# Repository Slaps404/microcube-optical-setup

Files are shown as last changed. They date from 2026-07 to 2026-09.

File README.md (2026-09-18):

# uCube optical setup

Parametric OpenSCAD parts for a 50 mm plate beamsplitter, M37 camera interface,
and a focus-adjustable illumination cell. The design is built around the
official uCube library and the measured 45 mm clear opening cube.

## Source of truth

- `optical_setup.scad` is the editable geometry source of truth.
- `DESIGN.md` records the active architecture, measured dimensions, provisional
  dimensions, and required physical tests.
- `exports/current` contains the tracked active printable STL pack. Historical
  `adjustable_*` files remain in that folder but are explicitly excluded in its
  README.

## Layout

- `optical_setup.scad`: all printable parts and assembly previews.
- `vendor/uCube`: official uCube library, with local fixes in `PATCHES.md`.
- `vendor/BOSL2`: pinned M37 thread-geometry dependency.
- `research`: sourced illumination research.
- `exports/current`: tracked printable STLs and their OpenSCAD entry files.
- `slicer`: resolved Ender 3 V2 profiles for 0.4, 0.2, and 0.1 mm nozzles.
- `scripts`: reproducible STL export, mesh checks, and slicer smoke tests.
- `previews/current`: curated images for documentation. Other QA renders under
  `previews/` are ignored by Git.

Initialize dependencies after cloning:

```sh
git submodule update --init --recursive
```

OpenSCAD is required for previews, validation, and STL export. On macOS with
Homebrew:

```sh
brew install openscad
```

## Active design

The optical cube uses the measured uCube geometry:

| Feature | Value |
| --- | --- |
| Clear through-hole | 45 mm |
| Frame feature | 7 mm |
| Overall cube | 73 mm |
| uFace plate | 59 x 59 x 3.5 mm |
| uFace corner screw centers | +/-26 mm |
| Mid-edge cube-to-cube screw centers | +/-29.5 mm |

The bottom uFace holds a measured 50 x 50 x 2.5 mm plate beamsplitter at 45
degrees. Its 2.4 mm printed slot is intentionally 0.1 mm undersized for final
fit by light filing.
The camera uFace provides a male M37 x 0.75 thread for the lens's female
front/filter thread. This is separate from the lens's camera-side C-mount.

Illumination uses a custom, light-tight cell bolted to one side uFace, not a
second official cube. The cell is 190 mm long, with a 180 mm clear interior
rail, and prints as two U shells: a
bottom shell with the mating plate, floor, far wall, and integral rail; and a
top shell that acts as the removable lid. The lid has five 45-degree-baffled
roof exhaust slots and four low side-intake slots behind an internal shroud.
A tongue-and-groove seam blocks a straight light path.

One centered 10.5 x 9 mm rail carries two independently clamped sliders:

- A 25 mm-deep lens sleeve for a purchased 40.0 mm lens tube. Its 1 mm inner
  lip stops the tube, and a 1.25 mm-wide internal spring-clip groove 5.25 mm in
  from the open rear retains it.
- An LED post for the 20 mm star MCPCB, with a cable pass-through below it.

Both sliders use opposing M3 heat-set-insert clamp screws. Their positions are
set on the bench to tune focus and illumination, rather than assumed from
optical estimates. The sleeve harness spans the full sleeve depth to center its
mass over the rail contact. The LED feature remains offset on its harness to
create one coplanar end face for support-free print orientation without
changing the modeled optical position.

The harness side runners rest directly on the bottom-U floor. The current
model gives a nominal 9 mm harness slot depth around the measured 9 mm rail,
so the slider seats on both the floor and the rail top.

Modes 2 through 4 are legacy compact-light parts. They remain in the source,
but are not part of the active design.

## Render modes

Set `render_mode` near the top of `optical_setup.scad`.

| Mode | Output |
| --- | --- |
| 0 | Complete optical assembly |
| 1 | Beamsplitter mounting face |
| 2-4 | Legacy compact light chamber parts |
| 5 | M37 camera mounting face |
| 6 | M37 thread-fit coupon |
| 7 | Exploded assembly reference |
| 8 | Inspection assembly reference |
| 9 | Official uCube shell |
| 10 | Illumination cell bottom U shell |
| 11 | Illumination cell top U shell, lid |
| 12 | Lens sleeve slider |
| 13 | LED post slider |
| 14 | Illumination cell assembly, lid on |
| 15 | Illumination cell assembly, lid off |

Modes 0, 7, 8, 14, and 15 are assembly or inspection views, not standalone
print parts. Export the other modes individually.

## Validate before exporting

Run a hard-warning validation before exporting an STL:

```sh
openscad --hardwarnings -o /tmp/optical_setup.csg optical_setup.scad
```

After changing geometry, render and inspect front, back, left, right, top, and
isometric previews. OpenSCAD validity confirms the model can render, not that
printed parts will fit.

Regenerate every active STL, check that each mesh is one connected watertight
surface, and run the Ender 3 V2 slicer smoke tests with:

```sh
scripts/export_printables.sh
scripts/slice_smoke_test.sh
```

GitHub Actions runs both commands and publishes the validated STL pack as a
build artifact. Slicer success catches toolpath and build-volume failures, but
does not replace physical fit coupons or first-layer calibration.

## Physical tests required

An initial cell and slider prototype has been printed. The revised 0.3 mm rail
fit and 25 mm sleeve still require physical verification. Test these coupons or
fit-critical features before another full print:

- One custom uFace on the physical cube, confirming outward-facing
  counterbores and fully seated screw heads.
- A rail segment and slider foot, confirming hand-sliding motion and secure
  clamp without rocking.
- A shallow lens sleeve, confirming the 40.0 mm tube slips in with minimal
  play.
- The M37 thread coupon, before the full camera face.
- Short bottom and lid seam sections, confirming the lid seats and blocks
  daylight.
- The 2.4 mm beamsplitter slot against the 2.5 mm plate, filing only enough for
  a secure seated fit.

Several values remain provisional, including heat-set insert dimensions,
optical clear aperture and focal data, cable routing, and the final focus
distances. See `DESIGN.md` for the full risk and test record.

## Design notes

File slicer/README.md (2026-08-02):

# Ender 3 V2 slicer smoke-test profiles

These are resolved PrusaSlicer profiles for an Ender 3 V2 using generic PLA
Pro assumptions. They exist to make slicing repeatable and to catch impossible
toolpaths, bed-size violations, disconnected meshes, and support requirements.

| Profile | Nozzle | Layer height | Intended parts |
| --- | ---: | ---: | --- |
| `ender3v2-pla-pro-04.ini` | 0.4 mm | 0.20 mm | Cell shells, cube, beamsplitter face |
| `ender3v2-pla-pro-02.ini` | 0.2 mm | 0.10 mm | Sliders and M37 camera face |
| `ender3v2-pla-pro-01.ini` | 0.1 mm | 0.05 mm | M37 thread-fit coupon |

All profiles use 205 C nozzle, 60 C bed, and three perimeters. Confirm the
temperature range printed on the actual PLA Pro spool before printing. These
profiles are smoke-test defaults, not a substitute for first-layer, flow,
retraction, and dimensional calibration on the physical printer.

Run:

```sh
scripts/export_printables.sh
scripts/slice_smoke_test.sh
```

Generated G-code is written under `build/` and intentionally ignored by Git.
Do not send CI-generated G-code directly to a printer without previewing it.

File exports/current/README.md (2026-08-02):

# Current printable STL pack

Generated from `optical_setup.scad`. Dimensions are millimeters. Each STL has a
matching SCAD entry file in this folder. The SCAD entry files load the shared
parametric source from the repository, so keep the repository structure intact.

The active Path B illumination cell is a four-part print, listed first below.

| File | Quantity | Render mode | Purpose |
| --- | ---: | ---: | --- |
| `illumination_cell_bottom_u.stl` | 1 | 10 | Cube-facing bottom cell, fused standard uFace, full-depth screw bores, floor, rail, and far wall |
| `illumination_cell_top_u.stl` | 1 | 11 | Cell lid, left wall, right wall, and roof only |
| `lens_sleeve_slider.stl` | 1 | 12 | 41 mm lens-tube sleeve and raised-clamp rail harness |
| `led_post_slider.stl` | 1 | 13 | LED post, bottom-open cable notch, and raised-clamp rail harness |
| `official_ucube_shell.stl` | 1 | 9 | Optical cube shell |
| `beamsplitter_mounting_face.stl` | 1 | 1 | Bottom 50 mm beamsplitter carrier face |
| `m37_camera_mounting_face.stl` | 1 | 5 | Camera face with male M37 x 0.75 thread |
| `m37_thread_fit_coupon.stl` | 1 optional | 6 | Short thread-fit test before printing the camera face |
The earlier `adjustable_*` and `collimator_retaining_ring` files are retained
only as historical exports. Do not print them for the active Path B cell.

## Ender 3 V2 slicer assignments

| Parts | Nozzle | Layer | Orientation and supports |
| --- | ---: | ---: | --- |
| Cell bottom, cube shell | 0.4 mm | 0.20 mm | As exported, automatic build-plate-only supports |
| Cell lid | 0.4 mm | 0.20 mm | Rotate X 180 degrees so the roof is on the bed |
| Beamsplitter face | 0.4 mm | 0.20 mm | As exported, no supports |
| Lens slider | 0.2 mm | 0.10 mm | Rotate Y 90 degrees, 3 mm brim, build-plate-only supports |
| LED slider | 0.2 mm | 0.10 mm | As exported, 3 mm brim, no supports |
| M37 camera face | 0.2 mm | 0.10 mm | As exported, no supports |
| M37 thread coupon | 0.1 mm | 0.05 mm | As exported, 2 mm brim, no supports |

The checked-in PrusaSlicer profiles assume 205 C nozzle, 60 C bed, and three
perimeters. Confirm temperatures against the actual PLA Pro spool. CI-generated
G-code is a smoke test and must not be sent directly to the printer without a
slicer preview and physical first-layer calibration.

Print the thread coupon and fit-critical rail, lens-pocket, and beamsplitter
features as tests before committing to the complete print. M3 insert pockets,
thermal hardware, focal spacing, and several rail anchor dimensions remain
provisional in the OpenSCAD source.

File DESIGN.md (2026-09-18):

# Microcube Optical Setup: Design Record

> **Status:** Active design context, pending physical prototype review
> **Updated:** 2026-08-14
> **Note:** Renamed from `proposed_plan.md`; the design is no longer a proposal.

---

## 1. Objective

A parametric, printable OpenSCAD optical assembly built around the official
uCube library. A 50 mm plate beamsplitter folds an illumination beam into a
camera path. Success means the parts align on the cube optical center, export as
valid individual STLs, and can be tuned on the bench without redesigning the
whole assembly.

Only mechanical 3D design is in scope. Raspberry Pi timing, LED driver
electronics, image acquisition, and image-combination logic are out of scope,
except that the printed design must permit cable routing and external thermal
hardware.

## 2. Cube geometry (MEASURED and locked)

The physical scaled cube is `size = 45, d = 7`. Two numbers that looked
contradictory describe two different features, and both measurements were right.

| Feature | Value |
| --- | --- |
| Clear square through-hole | 45 |
| Frame feature `d` | 7 |
| Overall cube | 73 |
| uFace plate | 59 x 59 x 3.5 |
| Corner screw centers (uFace mounting) | +/-26 |
| Mid-edge cube-to-cube screws | +/-29.5 |
| Outer surface to inner opening edge | 14 (`2d`) |
| Screw-pad inset width | 10.5 (`1.5d`) |
| Screw spec | `screwR 1.75, capR 3, capH 2.5, insertH 5, insertR 2` |
| faceGap | 0.4 |

The through-hole is `size` = 45. The wider inside-face inset is `size + 2d` = 59,
which measures about 60 by hand. `Scaled_uCube.scad` in Downloads carries
`mySize = 60`, which conflates the two and is **stale**. Do not treat it as a
source of truth.

## 3. Architecture

### Optical cube
Official `uCube` shell. The bottom face carries the beamsplitter at 45 degrees,
the top face carries the M37 camera interface for the downward-looking camera,
and one side face carries the horizontal illumination cell.

### Illumination cell (Path B)
A **custom light-tight box that bolts into one uFace pocket**, not a second
official cube. Reason: an official 73 mm cube has 14 mm end walls, so its
interior is only 45 mm along the light axis, which cannot hold a 25 mm sleeve
plus focus travel plus the LED post. Bolting through a uFace keeps official
screw compatibility while letting the box be as long as the optics need.

Prints as **two U shells**:
- **Bottom U:** mating plate, near end wall with the light port, floor, far end
  wall, and the integral rail.
- **Top U:** both side walls plus the roof, dropping on as a lid.

The top U includes passive ventilation near the LED end: five 20 x 3 mm roof
exhaust slots with 45-degree internal louvers, plus four vertical 12 x 3 mm
intake slots low on the positive-Y wall behind an offset internal shroud. The
separated low intake and high exhaust encourage passive convection. Both vent
groups remove the direct perpendicular light path, but physical light-leak and
temperature tests are still required. The side shroud has a 5.5 mm air gap,
giving its clear downward plenum about 146 mm2 of area versus 144 mm2 across
the four intake slots, so the hidden channel does not choke the visible slots.

Assembly and focus adjustment happen by lifting the lid, so there is no access
slot or cover strip. The top U is intentionally only the roof and upper side
walls, with no end-wall tabs or cross-pieces.

The enclosure is 73 mm wide at the body but retains the standard 59 mm uFace
mounting plate and its unchanged screw pattern. The outer cell is 190 mm long,
giving the full-length rail 180 mm of clear sliding room. This is based on the
roughly 170 to 175 mm occupied span in the bench reference photo, rounded up to
leave a little positioning margin.

The cell uFace uses the same cube-opening datum as the other custom faces. A
44.2 mm square, 1 mm-deep bridge crosses the cell-wall/uFace interface and
overlaps each solid by 0.5 mm. This makes the mount and bottom shell one
printable part while retaining 0.4 mm clearance per side in the measured 45 mm
cube opening.

### Rail and sliders
**One** centered rail runs the full interior length along the light axis,
10.5 x 9 mm. Its top is *derived*, not chosen: it sits 1.5 mm below the sleeve
underside to leave a solid harness roof while the bore stays exactly on the beam
axis. The slot roof rests directly on the rail top, with no vertical clearance.

Two sliders share one `harness_foot` module, so they grip identically: a
nominal-zero-clearance U straddling the 10.5 mm rail with two opposing M3 set
screws in heat-set inserts pressing the rail flanks. The modeled slot is now
10.5 mm wide. The printed rail and harness showed approximately 10.4 mm and
11 mm respectively, so this revision is an empirical tightening experiment;
print a short coupon and file only if needed.

The harness side runners rest directly on the bottom-U floor. Their nominal
slot depth is 9 mm around the 9 mm rail, so the slider seats on both the floor
and the rail top.

The latest printed fit measured a 10.4 mm rail width and 10.85 mm harness slot
width, or 0.45 mm total lateral clearance. It also measured 9 mm rail depth
against the original 7 mm harness slot depth; the revised 9 mm slot closes
that unsupported lower span and brings the runners onto the floor datum.

The sleeve harness spans the full 25 mm sleeve depth, making both end faces
coplanar and centering the modeled mass over its rail contact for support-free
printing and stable unclamped placement. The LED upper geometry remains offset
toward positive X relative to its harness so the harness front is flush with
the LED pad face. The sleeve and LED optical planes remain fixed.

Each insert bore is intentionally stepped. The 4.0 mm by 5 mm insert pocket
ends at a 1 mm backing shoulder, followed by a 3.2 mm screw passage to the rail.
The 0.4 mm radial shoulder stops the insert and keeps it out of the sliding
slot. Both slider types use the shared `m3_insert_diameter_mm` and
`m3_insert_length_mm` parameters. Final fit still requires a coupon with the
purchased insert.

- **Slider 1, lens sleeve** (one printed part): bore 41, wall 2, OD 45, depth 25.
  A 1 mm internal lip at the cube-facing end stops the purchased tube; the tube
  loads from the open rear and a 1.25 mm-wide internal circumferential spring-clip
  groove retains it 5.25 mm in from that rear edge. The groove has a 0.5 mm
  radial recess, leaving 1.5 mm of sleeve wall.
- **Slider 2, LED post:** a 22.8 mm-wide flat plate, flush with the harness
  sides, with its pad on the beam axis and a cable pass-through below the star
  footprint. The 20 mm star retains 1.4 mm of support per side.

### Optics
The two lenses ride on spring clips inside a **purchased 40.0 mm lens tube**
(measured, smooth outer surface). Our sleeve holds that tube. We neither model
nor machine the tube.

### Light source
Amazon ASIN B0CL726PBP: 3 W 3535 emitter on a 20 mm star MCPCB, 3.0-3.4 V at
700 mA, 120 degrees, 8000-10000 K. For v1 the star is taped or glued to the
post. **v1 strobes the LED, so no secondary heatsink is modeled** and the star's
own MCPCB is the only thermal mass. Capturing the star's edges or adding a
glued-on heatsink is a v2 change to one small part, not to the cell.

A 120 degree emitter spills a cone far wider than the lens, so **closer is
brighter**. Travel toward zero gap is worth more than travel past 25 mm. V1 is
limited to short-duration operation. The passive vents reduce trapped heat but
do not replace a heatsink for continuous use.

### Camera interface
Male M37 x 0.75 printed thread engaging the lens's female front/filter thread.
The lens's camera-side C-mount is a separate interface.

## 4. Key decisions and rationale

| Decision | Chosen approach | Rationale |
| --- | --- | --- |
| Cube size | `size = 45, d = 7` | Physical measurement. The 60 in the Downloads file is the inset, not the bore. |
| Screw counterbores | Z mirror in `official_face_at_inside_plane()` | The vendor uFace opens counterbores on plate local +Z, but every custom face builds toward the cube interior on +Z, so cap screws could not seat from outside. One mirror fixes all five faces with no vendor edits. `uHolder.scad` performs the same flip. |
| Illumination packaging | Custom box on a uFace (Path B) | A second official cube has only 45 mm of usable length. Path B also gives 2 seams instead of 6 face perimeters to light-seal, a solid floor for the rail, and an interior we control. |
| Cube rescaling | Rejected | Print time and setup time are the binding constraints. Prefer local geometry changes. |
| Rail count | One centered rail | It bridges the center of one end to the center of the other, which also dissolves any collision with the corner inserts. |
| Rail height | Derived from the sleeve | Centering the bore on the beam axis outranks rail height. |
| Rail sliding fit | 0.3 mm total lateral, 0 mm vertical | Physical prints showed excessive play at 1.0 mm total. The tighter 0.15 mm-per-side slip fit reduces rocking; direct top seating prevents optical-axis drop before clamping. |
| Harness side depth | 9 mm slot depth around 9 mm rail, 0 mm floor clearance | Seats the side runners on the bottom-U floor while the slot roof seats on the rail top. |
| Beamsplitter fit | 2.4 mm printed slot for measured 2.5 mm plate | The intentional 0.1 mm interference is removed by light filing until the plate seats securely. |
| Lens retention | Purchased tube, spring clip, 1 mm lip, 1.25 mm-wide internal groove | The lip fixes the cube-facing end. The rear groove gives the clip a positive seat while retaining the tube-in-tube fit. |
| Sleeve wall | 2 mm | Path B frees the interior size, so the earlier 1 mm workaround is unnecessary and would print weak. |
| Focus adjustment | Two independently clamped sliders | Both LED and lens positions must be tuned empirically. |
| Thermal design | Baffled passive vents, no heatsink in v1 | Short-duration operation limits heat input. Low side intake and high roof exhaust reduce trapped heat, but continuous use still requires a measured thermal solution. |
| Slider print faces | Full-depth sleeve harness; offset LED feature | Coplanar end faces let both sliders print on their backs without supports. The full-depth sleeve foot also centers its modeled mass over the rail contact while preserving the optical plane. |
| Harness wall | 6 mm | A 5 mm heat-set insert cannot live in a 3 mm wall. Enforced by assert. |
| Harness insert shoulder | Retained | The insert pocket needs a depth stop; the smaller continuation gives the clamp screw access to the rail. |
| Cell-to-cube interface | Standard uFace plus 44.2 mm bridge | The uFace enters the standard cube slot, while the bridge overlaps the cell wall and face so they slice as one connected part. |
| Post mount face | The side face opposite the illumination cell | The cell hangs its whole mass off one cube face. Mounting opposite turns that into a pitch moment in the plane of the gusset, which the tall backplate and the vertically separated M5 bolts resist directly. A 90 degree mount would turn the same load into roll about the post, which shows up as image rotation. |
| Post standoff | 72 mm from the post mating face to the cube center | The backlight short side measures 149.9 mm, so half of it is 74.95 mm. 72 mm puts the cube center just inside the backlight center and still leaves 30 mm of gusset between the uFace and the backplate. |
| Post interface | Three-sided socket, 0.2 mm total width clearance, 4 mm walls, 14 mm deep | The broad flanks set the pose against the extrusion so the two M5 bolts only supply clamp force, not alignment. The 0.2 mm is a starting guess and is what the socket coupon exists to check. |
| M5 hole position | Round 5.5 mm holes at Y +/-43 | The T-nut sits in the post slot on the cube centerline, so each bolt head faces the cube. Both holes have to sit far enough out along Y that a bolt head plus a washer clears the 73 mm cube envelope. That, not the plate, is what sets the 105 mm backplate height. |
| Round holes, not slots | Plain through-holes rather than the reference bracket's pill slots | The T-nut already slides freely along the post slot, so the bracket sets its own height by where it is clamped. Slots would only add material and a stress riser at the most heavily loaded part of the plate to buy travel that is already available. |
| M5 head approach | 3 mm straight pocket, then a bell flaring to a 24 mm mouth. Its rise is DERIVED, currently 16.45 mm | The bolt head faces the cube, so a hex key has to come back out through the gusset. The flare edge does not recede inboard of a 9 mm driver until Z=-25.55, so the bell has to reach past that or a shelf of gusset caps it. A typed-in 9 mm rise left exactly that shelf, 2.7 mm thick, and no key could reach the bolt. The rise is now computed from the flare rate and asserted. |
| M5 driver clearance | 9 mm straight run on the bolt axis, verified by swept-cylinder intersection | Both fastener sets are checked by sweeping a driver cylinder along its access axis and intersecting it with the bracket plus the 73 mm cube envelope. M3 measures clear to 6.0 mm and M5 to 9 mm. The M5 figure is held two full mm under the 11 mm funnel throat: the throat is a 72-sided polygon, so a nominally equal driver binds on facets. |
| M5 funnel throat | 11 mm, sized for a washer and not just the head | A bare M5 socket cap bears on 33 mm^2, which is 30 MPa at 1 kN of preload. A DIN 125 washer takes that to 55 mm^2 and 18 MPa. PLA creeps well below yield under permanent load, so that margin is the difference between a joint that holds and one that needs re-torquing. The washer OD is 10.0 mm, but the throat is a 72-gon, so a nominal 10 measures 9.99 across the flats and would not pass it. 11 is the next step up. |
| Print settings | The shared 0.4 mm profile as-is, 15 percent grid and 3 perimeters, plus one manual solid modifier around the two M5 seats. Sliced that way it is 69 g and 6h47m, of which about a seventh of the filament is buildplate-only support under the plate ledge | Infill is not the strength lever here. The gusset root has a section modulus of about 49,900 mm^3, so the 5 N cell load at a 72 mm arm works the root to 0.003 MPa, which is 0.01 percent of PLA interlayer strength, and models a 0.00007 mm tip deflection. Raising infill to 20 percent gyroid and adding a fourth perimeter was measured at 82 g and 8h40m, so it spends 13 g and two hours on a section that is already 4 orders of magnitude oversized. What actually governs is local bearing and creep where the bolts clamp, which is why those seats get solid material and a washer instead. `led_post_slider` is a 3.8 g part with nothing structural in it, so raise its infill only to give the clamp-screw heat-set insert bite in the 6 mm harness wall. Its real limit is heat, since v1 has no secondary heatsink and PLA softens near 60 C. |
| M3 screw pitch | 26.0 mm, derived from the vendor formula `0.5*(faceSize - d)` | Deriving it from `face_outline_mm` instead put every passage 0.4 mm per axis, 0.57 mm radially, off the real hole. That is enough to shave an M3 clearance passage below the 3 mm shank. The same expression was wrong in `cell_mating_screw_passages()` and is now corrected there too. |
| M3 cap reliefs | 6.0 mm bores, depth DERIVED, currently 13.2 mm | The gusset buries the four vendor counterbores, so each needs a corridor bored through it. 6.0 mm matches the vendor counterbore exactly (`capR = 3`) and is the widest bore that does not breach the 0.1 mm of plate rim left at the corner. The depth is computed from where the flare edge pulls inboard of the bore, the same rule as the M5 bell, instead of the magic 20 mm it used to be. |
| Gusset weld band | The 0.5 mm root overlap is clipped to vendor plate material and inset 0.1 mm inside the plate outline | The gusset root is a plain square slab. Unioned raw, it silently re-filled the voids the vendor plate cuts for itself: the four mid-edge notches that clear the cube's retaining tabs, and the four cap counterbores. Both defects render as valid watertight manifolds, so `Simple: yes` never caught them. Clipping the band to vendor material means the overlap can only add where the plate is already solid. The 0.1 mm inset is separate: the gusset is already flaring in Y by the time it reaches this band, so flush with the plate outline would put 0.37 mm out into the cube's 0.4 mm face gap. With the inset, the boolean against the cube measures exactly empty. |
| Weld band written as one difference | Not as two stacked solids meeting at the plate plane | The stacked form duplicated a face across the whole gusset cross-section. CGAL and the exported STL were fine, but OpenCSG preview z-fights on duplicated faces and drops surrounding surfaces out of the picture, which reads as clipping through the part. |
| Post mount print orientation | uFace flat on the bed, gusset growing upward | Layer lines then run across the bending stress rather than along it, and the flaring gusset is its own printing support for the backplate that overhangs it. The flare is asserted to stay inside 45 degrees; it currently runs at 37.95 degrees over a 30 mm rise. |
| No coved root fillets | The flare is the cove | The reference bracket's cove fills the inside corner of an L. Here the uFace and the backplate are parallel and 30 mm apart, so there is no corner to fill. A concave arc between the same endpoints, held inside the overhang budget, only scoops about 1.4 mm out of a 30 mm run, which is below what the printer resolves. |
| Gusset lightening | Three 14 mm round windows on the neutral axis, 17 mm pitch | Bending stiffness comes from material out at the flare, so the material near Y=0 is nearly free to remove. The windows are bored along X, so printed uFace down their axes lie in the build plane and each bridges its own crown. Only the centre window actually sits on the neutral axis; the outer two trade a little stiffness for a lot of mass. |
| Which cube face | Any of the four side faces | The light axis must be horizontal so the sliders sit on a floor. The cube is 4-fold symmetric, so the printed part is identical whichever side is chosen. Picked at assembly time, not design time. |

## 5. Dependencies and repository state

| Library or tool | Purpose | Location |
| --- | --- | --- |
| OpenSCAD | Parametric CAD, preview, STL | `C:/Program Files/OpenSCAD`; validate with hard warnings. |
| PrusaSlicer | Ender 3 V2 toolpath smoke tests | Resolved 0.4, 0.2, and 0.1 mm nozzle profiles under `slicer/`. |
| Official uCube library | Cube shells and uFaces | `vendor/uCube`; fixes documented in `PATCHES.md`. |
| BOSL2 | M37 thread geometry | Pinned under `vendor/BOSL2`. |
| GitHub | Source and exports | `Slaps404/microcube-optical-setup`, branch `main`. |

## 6. Open questions and known risks

- **An initial cell and slider prototype has been printed.** Its measured
  printed rail and harness were approximately 10.4 mm and 11 mm, or about
  0.6 mm total play. The modeled fit is now nominally 0 mm total clearance;
  this still needs a physical coupon because OpenSCAD validity does not prove
  printer tolerance.
- **Sleeve depth 25 mm is confirmed against the purchased tube.**
- **Spring-clip groove fit is unprinted:** the current groove is 1.25 mm wide,
  5.25 mm axially in from the open rear, and recessed 0.5 mm radially. Test
  the actual spring clip and tube together before committing to the full print.
- **M3 insert fit is unprinted:** the current cell harness pocket is 4.0 mm
  diameter by 5.0 mm deep, followed by a 3.2 mm screw passage. The passage
  center is 3.6 mm below the rail top, leaving 2.0 mm of rail-top clearance
  above the passage and 1.6 mm above the insert pocket. This leaves a 0.4 mm
  radial shoulder and 1 mm axial backing wall. The complete fit still needs a
  printer/material coupon with the purchased insert.
- **Seam clearances are untested.** The 0.25 mm lid slip fit and the
  tongue-and-groove both need a printed coupon.
- **Light-tightness is unproven.** The vent louvers and intake shroud block the
  direct perpendicular path, but oblique leakage through the vents and leakage
  at the removable lid seam still require a dark-room test. Plan on 3
  perimeters or a matte black interior.
- **Passive cooling is unproven.** The vents are appropriate only for the
  planned short-duration LED operation. Measure LED-board and enclosure
  temperature before increasing duty cycle; vents are not a heatsink.
- **The LED post is a thin tall cantilever.** It carries only a 2 g board, but
  check stiffness and print quality on the first article.
- **Optical data is provisional:** clear aperture, EFL 40 mm, and BFL 26 mm are
  not confirmed measurements.
- **The cell bottom sits 0.5 mm below the cube bottom**, since the floor wall is
  4 mm where 3.5 mm would be flush. Cosmetic on a benchtop.
- **Cable path needs physical definition** beyond the pass-through notch.
- **External frame mounting is dimensioned but unprinted.** `post_mount` is a
  blank side uFace that flares into a 28.2 x 105 x 6 mm backplate with a
  three-sided socket for the post. It replaces the lab clamp that loaded the
  whole optical head through the lens barrel. The camera still needs its own
  support on a separate horizontal extrusion above the cube; that is not
  designed. Open items on this part:
  - The post is confirmed as standard 20 x 20 mm T-slot extrusion with one
    centered slot per face, but the **slot opening width and T-nut thread are
    still unconfirmed**. The design assumes M5 T-nuts.
  - The 0.2 mm total socket clearance is a guess. Print
    `post_mount_socket_coupon.stl` first.
  - The socket walls now wrap 18 mm of the 20 mm post section while retaining
    the 0.2 mm total width clearance.
  - **The part is large.** 121 cm^3 of enclosed volume, 58.2 x 105 x 60.5 mm,
    which is a long print. If print time turns out to be unacceptable, the next
    step is replacing the solid gusset with three flaring ribs, which models to
    roughly 90 cm^3 but adds bridging under the backplate.
  - **PLA creep is a real risk here.** The bracket is permanently loaded in
    bending by the cantilevered illumination cell. Prefer PETG, or plan to
    re-check alignment over time.
  - The earlier one-tab C-frame concept is rejected as too flexible; see
    `research/optical-head-frame-integration.md`.
- **The complete-assembly preview has the camera on a side face, which does not
  match the physical downward-looking setup.** The printable M37 face itself is
  orientation-neutral. Correct the preview transform in a separate geometry
  task after the external frame concept is selected.
- **Future illumination optics need a frame-supported expansion rail.** Preserve
  a horizontal rail datum through the center of the illumination uFace so a
  longer train, including field and aperture diaphragms for Köhler illumination,
  does not cantilever from the printed cube face.
- **Focus distances must be set empirically.** The ~2 cm LED-to-lens figure is a
  guess, not a measurement. Both sliders adjust, so nothing depends on it.
- The active Path B cell has individual export entry points for its bottom U,
  top U, lens slider, and LED slider. The older adjustable-collimator files in
  `exports/current` are historical and must not be mixed into this assembly.

## 7. Testing considerations

| What to test | Method | Success criteria | Phase |
| --- | --- | --- | --- |
| Face screws | Mount one custom uFace on the real cube | Counterbores face outward and cap screws seat fully | Fit coupon, do this first |
| Rail and harness | Print a short rail section and one foot | Foot rests on the floor and rail, slides by hand without binding, and clamps without rocking | Fit coupon |
| Sleeve bore | Print a shallow sleeve ring | The 40.0 mm tube inserts without force, minimal play | Fit coupon |
| Sleeve spring clip | Print a shallow sleeve ring with the rear groove | The spring clip seats fully, retains the tube against the 1 mm lip, and can be removed without damaging the tube | Fit coupon |
| M37 thread | Print `m37_thread_fit_coupon.stl` | Lens engages smoothly without splitting | Fit coupon |
| Lid seam | Print short sections of both U shells | Lid drops on and the seam has no objectionable light leak | Fit coupon |
| Beamsplitter slot | File the 2.4 mm slot for the measured 2.5 mm plate | Plate seats securely without edge stress; supports hidden in side view | Bench assembly |
| Light-tightness | Assemble, light the LED, darken the room | No visible leak at seams or through the walls | Bench assembly |
| Passive ventilation | Run the intended short-duration LED sequence and measure the LED board and enclosure | Temperatures remain within the purchased LED and material limits; stop if they continue rising | Bench assembly |
| Illumination | Sweep both sliders with the real LED | Even field on the cube face without imaging the emitter | Optical prototype |
| Post socket fit | Print `post_mount_socket_coupon.stl` and slide it onto the real extrusion | Socket seats flat on the post face with no rock, slides on by hand, and an M5 T-nut bolt pulls it tight without spreading the walls | Fit coupon, do this before the full bracket |
| Post mount bolt access | Offer the printed bracket up to the post with the cube attached | A hex key reaches both M5 heads without fouling the cube, and the bell lets the screw start off-axis. The CAD says clear to a 9 mm driver; confirm with the real key and the real cube | Bench assembly |
| Post mount stiffness | Mount the loaded head and check for sag and drift | No visible tilt, and alignment holds over the run; recheck after a week for creep | Bench assembly |
| Mesh validation | Hard warnings plus six-view inspection | Every printable mode reports `Simple: yes` | Every CAD revision |
| Slicer validation | Slice all ten active STLs with the assigned Ender 3 V2 profile | G-code is produced without slicer errors or bed-volume failures | Every CAD revision |

## 8. Render modes

| Mode | Part |
| --- | --- |
| 0 | Complete assembly |
| 1 | Beamsplitter mounting face |
| 2-4 | Legacy compact light chamber (retained, not the current design) |
| 5 | Camera face |
| 6 | Camera thread test coupon |
| 7 | Exploded assembly |
| 8 | Inspection assembly |
| 9 | Official uCube shell |
| 10 | Illumination cell bottom U |
| 11 | Illumination cell top U (lid) |
| 12 | Lens sleeve slider |
| 13 | LED post slider |
| 14 | Cell assembly |
| 15 | Cell assembly, lid off |
| 16 | Post mount |
| 17 | Post mount socket fit coupon |
| 18 | Condenser carrier |
| 19 | Collector carrier |
| 20 | LED carrier |
| 21 | Carrier foot fit coupon |

Modes 18-21 build with whichever foot `carrier_rail_kind` selects. The eight
entry files under `exports/current/` pin the foot per part instead, because a
file-scope assignment in `optical_setup.scad` cannot be overridden from an
including file.

## 9. Separate-optic carriers

The Koehler retrofit puts the collector and the condenser `f1 + f2 = 16 + 40 =
56 mm` apart at their principal planes. That does not fit one 25 mm sleeve or
one 40 mm lens tube, so the two optics move onto independent carriers that
slide to set focus. This supersedes the single `lens_sleeve_slider` for the
retrofit; the old slider is retained and unmodified.

Both supplied lenses are 40.0 mm diameter (spherical collector, aspheric
condenser), so one cell geometry serves both and only the stack length
differs. The cell deliberately reuses the legacy sleeve envelope: 41 mm bore,
45 mm OD, same spring-clip groove.

That reuse is the load-bearing decision. A printed threaded retaining ring
needs a thread major larger than the 41 mm bore, which pushes the cell OD past
50 mm, which pushes the rail datums 3 mm lower and breaks compatibility with
the existing printed cell. The supplied set already solves retention without
any of that: the lens seats on a 38 mm front lip, the supplied 40 OD / 38 ID /
13 mm divider ring sits behind it as a flat pressure washer, and the spring
clip loads the divider. The clip never touches glass, and the two annular
lands that clamp the lens have the same 38 mm ID, so the load is symmetric.

Two feet are provided for the same carriers, chosen by `carrier_rail_kind`:

- `0`, 2020 extrusion: an inverted U with a 20.2 mm straddle slot open
  downward, 5 mm side walls, and one M5 per side into a T-nut in the
  extrusion's side slot. The holes sit on the extrusion's vertical
  centerline, which is the height of the side T-slot. Round holes, not slots,
  for the same reason as `post_mount`: the T-nut already slides. Each hole is
  counterbored 2.5 mm at 11 mm on a 72-gon for a DIN 125 M5 washer, leaving a
  2.5 mm bearing wall. Inside corners of the slot are relieved 1.6 mm for the
  extrusion's corner radii; unlike `post_mount`'s reliefs these run along X,
  because here the slot runs along the light axis rather than across it.
- `1`, printed rail: the legacy `harness_foot` reused unchanged. Its rail
  datums derive from `sleeve_outer_mm`, and the carrier cell keeps that same
  45 mm OD, so it drops onto the existing rail section with no new rail
  parameters. Only its length along X changes, from 25 mm to 16 mm, so more
  of the rail is focus travel.

Lens center thicknesses are PROVISIONAL (`collector_lens_thickness_mm = 14`,
`condenser_lens_thickness_mm = 18`) and set the cell lengths. Measure both
elements and correct these before printing a full carrier.

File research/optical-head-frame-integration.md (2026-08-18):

# Optical head frame integration concepts

**Status:** Brainstorming record, not an adopted geometry decision  
**Date:** 2026-08-16

## Problem

The current lab setup clamps the 16 mm lens. The uCube screws onto the front of
the lens, and the illumination cell bolts to the uCube. This makes the lens
barrel the structural spine for the entire optical head.

That arrangement has three problems:

1. The camera, uCube, and illumination cell form a long twisting lever around
   the lens clamp.
2. Tightening or bumping any downstream part can rotate or tilt the optical
   assembly.
3. The frame does not independently constrain the camera axis, cube position,
   or illumination axis.

The lens connection should locate the optical path. It should not be the main
structural load path.

## Design principle

Use **two strong load paths and one shared post datum**:

- Support the uCube directly from a broad adapter on the vertical extrusion.
- Support the camera directly from a separate horizontal extrusion and camera
  plate above the cube.
- Keep the camera lens axis vertical and coaxial with the center of the uCube.
- Keep the lens-to-uCube connection for coaxial optical alignment and light
  sealing, with little or no structural load.
- Let the uCube side face establish the illumination axis at 90 degrees to the
  vertical camera axis.

The camera and uCube are not orthogonal to each other. Their centers are on the
same vertical optical axis. The orthogonal relationship is between that camera
axis and the horizontal illumination axis.

```mermaid
flowchart TD
    P[Vertical extrusion post] --> A[Wide uCube backplate and lower saddle]
    P --> E[Horizontal camera extrusion]
    E --> G[Opposed corner brackets and gussets]
    G --> C[Horizontal camera plate]
    C --> B[IMX477 board or captive tripod cradle]
    B --> L[16 mm lens pointing down]
    A --> U[uCube]
    L -. coaxial optical connection, not main load .-> U
    U --> I[Illumination cell on adjacent cube face]
    I -. 90 degrees .-> L
    P --> R[Separately supported horizontal accessory rail]
    R --> K[Illumination modules, including Kohler]
    K --> I
```

## Recommended concept

### 1. Broad post interface, not a one-tab hanger

The small single contact shown in the first concept is not acceptable. Both
supports must spread load across the vertical extrusion.

The camera arm should meet the post with two opposed metal corner brackets or
gussets, preferably backed by a plate that uses multiple T-nuts. The uCube
adapter should contact the post over a tall, flat region with upper and lower
fasteners. If the post exposes two slot columns, use both columns to create a
rectangular four-bolt pattern.

The screws provide clamp force. Broad mating faces, gussets, shoulders, and
keys should define squareness and carry shear. One screw or one small printed
tab should not define the pose of either optical assembly.

The stand uses standard 2020 T-slot extrusion, so the outside section is 20 x
20 mm with one centered slot on each face. A single face therefore cannot
provide a two-column bolt pattern. Use two vertically separated fasteners in
the rear slot plus wraparound features or fasteners into the side slots.

### 2. Direct post-mounted uCube adapter

**Status: built as `post_mount` (render mode 16).** What follows is the concept.
See "As-built post_mount" at the end of this document for what was actually
modeled and where it departs from the concept.

The preferred cube support is a replacement rear uFace that grows into a
post-mounting backplate. It uses the existing four M3 face screws on a 52 mm
square pitch, so the uCube remains registered by its normal face geometry. The
plate extends above and below the 73 mm cube so its T-slot bolts remain
accessible after the cube is installed.

Add a short horizontal saddle under the cube and two shallow side cheeks:

- The saddle carries gravity in compression instead of asking the four M3
  screws to carry all weight in shear.
- The side cheeks register the 73 mm cube and resist yaw.
- The four uFace screws clamp the cube against the adapter.
- Upper and lower post bolts, widely separated along the post, resist pitch.
- Two wraparound post saddles, one above and one below the cube center, contact
  the front and side faces of the 20 x 20 mm post. Side-slot fasteners or fitted
  side walls resist roll and yaw better than relying on friction in one slot.

This adapter belongs on an unused face, preferably opposite the illumination
cell. It must leave the top camera port, bottom/sample path, illumination port,
and all needed face screws accessible.

A machined aluminum backplate with printed locator blocks is the stiffest
version. A fully printed PETG or nylon saddle is appropriate for the first fit
test, but it should have broad ribs and should not be treated as a proven final
instrument mount until deflection is measured.

The uCube becomes the local optical datum. Its vertical centerline defines the
camera axis, and its side face defines the horizontal illumination axis.

### 3. Independent camera support on a horizontal extrusion

Attach a horizontal extrusion above the uCube. Join it to the vertical post
with opposed corner brackets or gussets on both sides, not one small connector.
A camera plate spans between two brackets below the horizontal extrusion and
supports the IMX477 camera while its 16 mm lens points vertically downward into
the top uCube face.

Two camera attachment approaches are viable:

| Approach | Strengths | Risks | Best use |
| --- | --- | --- | --- |
| Four PCB holes on 30 mm square pitch | Positive anti-rotation, compact, repeatable | Requires correct standoffs, screw length, back-side keepouts, and cable access | Final rigid instrument |
| Captive tripod-foot cradle with one 1/4-20 bolt | Does not load the PCB, fast to install | The screw alone is one point, so the cradle must add a broad base and two side cheeks | First prototype or removable camera |

The tripod version is not a single-contact mount if the foot sits in a fitted
pocket. The bolt supplies clamp force, while the base plane and two locating
walls prevent yaw and rotation.

For the final fixed setup, the four PCB holes are the more direct way to make
the camera body independently rigid. Use four equal-height standoffs and verify
component clearance on the rear of the board.

### 4. Avoid fighting constraints

The M37 lens-to-uCube thread and the separate camera plate can both constrain
the same camera position. If they are tightened while misaligned, they can bend
the camera plate, load the lens barrel, or tilt the uCube.

Use this assembly sequence:

1. Rigidly mount and square the uCube on the post adapter and lower saddle.
2. Loosely mount the IMX477 camera in the camera plate.
3. Lower or slide the camera plate until the 16 mm lens engages the top uCube
   interface without side load.
4. Use slots or thin shims to remove any gap and align the support.
5. Tighten the camera support while watching for image shift.
6. Mark the final shim stack or slot position for repeatable reassembly.

The camera support should be stiff after tightening, but vertically adjustable
during first alignment. Slots in the paired camera brackets, or shims under the
camera plate, prevent the support from steering the lens.

### 5. Illumination cell support

The illumination cell should remain bolted to the adjacent uCube face. That
face establishes its 90-degree relationship to the camera axis.

If physical testing shows far-end sag, add a light vertical hanger from the
head plate to the far end of the cell. Use a slot at the hanger so it carries
vertical weight without pulling the cell sideways or redefining its optical
axis.

### 6. Expansion interface for Köhler illumination

Do not make the uCube carry a long train of future illumination optics. Add a
horizontal accessory rail whose centerline is fixed to the center of the
illumination uFace, but whose structural load returns directly to the vertical
post or base frame.

The uFace then provides optical registration and light sealing. The rail carries
the mass and bending moment.

A future epi-illumination train could provide independently sliding modules for:

1. LED or other source.
2. Collector lens.
3. Field diaphragm.
4. Relay optics.
5. Aperture diaphragm at the appropriate conjugate plane.
6. Condenser or final coupling lens into the uCube.

Exact order and spacing must follow the chosen Köhler optical prescription. The
mechanical requirement now is to preserve enough rail length and give every
module the same horizontal optical center height.

Possible rail standards:

| Rail | Strengths | Risks |
| --- | --- | --- |
| Two parallel cage rods | Strong control of rotation and optical center | Requires accurate rod spacing and parallelism |
| Dovetail optical rail | Rigid and easy to reposition | Purchased hardware can be expensive |
| 2020 extrusion with registered carriages | Matches the stand and is inexpensive | A single slot does not guarantee optical-axis rotation without a keyed carriage |

The most important requirement is two separated locating features. A single
round rod or one loose T-slot leaves module roll underconstrained.

Reserve a similar vertical expansion zone above the uCube. A removable spacer
or vertically sliding camera plate would allow future filters, analyzers, or
relay optics between the cube and camera without redesigning the post mounts.

## Structural load paths

- Camera: camera board or tripod cradle -> camera plate -> paired brackets ->
  horizontal extrusion -> opposed post gussets -> vertical post.
- uCube and beamsplitter: cube body -> rear mounting uFace -> lower saddle and
  tall backplate -> multiple T-nuts -> vertical post.
- Illumination cell: uCube face -> post-mounted cube adapter -> vertical post.
- Optional cell support: far-end hanger -> post or base frame.
- Future illumination train: accessory rail -> post or base frame.
- Lens connection: optical centering and sealing, not the primary support.

## Orthogonality checks

Mechanical squareness is necessary but not sufficient. Validate in this order:

1. Check the uCube backplate against the post with a machinist square.
2. Check the horizontal camera extrusion at 90 degrees to the post.
3. Check that the camera plate is parallel to the top uCube face.
4. Confirm the uCube is seated on its saddle and side registers before
   tightening screws.
5. Project or image a centered target through the system and watch for image
   shift while tightening the camera support.
6. Confirm the vertical camera axis is centered through the top and bottom cube
   openings.
7. Confirm the illumination axis enters through the center of its horizontal
   uCube face at 90 degrees to the camera axis.
8. Recheck after attaching the illumination cell, because its cantilever load
   can reveal cube or arm flex.

## Stability check before calling the mount complete

The image is not enough to certify stiffness. The post profile, arm length,
bracket material, fasteners, and real assembly mass are still unknown.

The current active STL set has about 404 cm3 of printed material including the
uCube shell and `post_mount`. At 1.24 g/cm3 this is roughly 502 g of PLA at 100
percent material density. This is only a mesh-volume estimate. It does not include the camera,
lens, glass, LEDs, wiring, fasteners, unused faces, or slicer-dependent infill
and wall settings. Weigh the complete physical head instead of using this
estimate for the final calculation.

For each cantilevered load, calculate the post-joint moment from
`moment = mass x 9.81 x horizontal reach`, using kilograms and meters. Then use
the real extrusion manufacturer's section data and the actual bracket pattern
to check deflection. Do not certify a profile guessed from the screenshot.

Physical proof test:

1. Square and focus the complete system on a fixed crosshair target.
2. Record the target position in camera pixels.
3. Add a temporary 1.5 times service load at the real center-of-mass location.
4. Record camera-to-cube image shift, not only motion of the extrusion tip.
5. Remove the load and confirm the image returns with no permanent shift.
6. Attach and remove the illumination cell and repeat, because it produces the
   strongest twisting load on the cube adapter.
7. Recheck every T-slot fastener after the first several assembly cycles.

Set the allowable pixel shift from the imaging experiment. A made-up mechanical
deflection limit would not prove that the optical result is acceptable.

Also inspect the upright-to-base joint. If the visible triangular plate is the
only base gusset, add an opposed gusset or backing plate so the whole post does
not rack even when the optical head itself is stiff.

## Pulled reference models

Reference meshes are stored under
`vendor/raspi-hq-camera-reference/`:

- `HQ_Camera_model.stl`
- `Lens_16mm_model.stl`
- `raspi_HQ_cam_and_16mm_lens.stl`

They came from David Crook's community OpenSCAD model at commit
`4951fc2d117aa58dec62e8bc2101ca5e6f0dc89c` and are licensed CC BY-SA
4.0. They are reference envelopes, not official manufacturing CAD.

The main dimensions were checked against Raspberry Pi's current documents:

- HQ camera PCB: 38 x 38 mm.
- Four board holes: 30 mm square pitch.
- Tripod thread: 1/4-20 UNC.
- 16 mm lens: approximately 39 mm diameter by 50 mm nominal length.

## Dimension authority

The concept render deliberately separates known component geometry from
provisional support geometry.

| Item | Current value | Authority | Status |
| --- | ---: | --- | --- |
| uCube overall size | 73 mm | `DESIGN.md` and current source | Locked physical measurement |
| uCube clear opening | 45 mm | `DESIGN.md` and current source | Locked physical measurement |
| uFace size | 59 x 59 x 3.5 mm | `DESIGN.md` and current source | Locked project geometry |
| uFace corner screw pitch | 52 mm square | `DESIGN.md` and current source | Locked project geometry |
| IMX477 HQ camera PCB | 38 x 38 mm | Raspberry Pi drawing | Official |
| Camera PCB holes | 30 mm square pitch, nominal 2.5 mm | Raspberry Pi drawing | Official, verify the physical board before screw selection |
| Camera tripod thread | 1/4-20 UNC | Raspberry Pi drawing | Official |
| 16 mm lens envelope | 39 mm diameter x 50 mm nominal length | Raspberry Pi documentation | Official envelope |
| Combined camera and lens mesh | 39 x 51.7 x 72.0222 mm bounding box | Imported community reference mesh | Packaging reference only |
| Beamsplitter | 50 x 50 x 2.5 mm | Physical measurement recorded in this project | Measured |
| Vertical post and camera-arm envelope | 20 x 20 mm, one centered slot per face | User identification as standard 2020 T-slot | Confirmed outside envelope |
| Slot opening and compatible T-nut | Commonly 6 mm slot with M5 hardware | Manufacturer-dependent 20-series interface | Verify the physical nut before modeling |
| Post-adapter height, thickness, and T-slot fasteners | Unknown | Depends on measured stand and chosen material | Concept only |
| Köhler rail spacing and module lengths | Unknown | Depends on the optical prescription | Concept only |

The black camera/lens mesh, uCube shell, and blue illumination cell in the
first concept render use the available reference geometry. Its orange one-tab
C-frame is rejected because it does not spread load into the vertical post.
It is not a printable support part and should not be used for fabrication.

Sources:

- [Raspberry Pi HQ camera mechanical drawing](https://datasheets.raspberrypi.com/hq-camera/hq-camera-mechanical-drawing.pdf)
- [Raspberry Pi camera documentation](https://www.raspberrypi.com/documentation/accessories/camera.html)
- [Community reference model source](https://github.com/idcrook/psychic-winner/tree/main/raspi_cam_hq_models)

## Measurements needed before CAD

- Confirm the horizontal arm is also 2020, not only the vertical post.
- Measure the slot-mouth width and identify the existing T-nut thread. Start
  from a 6 mm slot and M5 only after physically confirming the hardware.
- Confirm which front and side post slots remain accessible at the cube height.
- Maximum possible vertical spacing between the upper and lower cube-adapter
  bolts.
- Available horizontal camera-arm length above the uCube.
- Desired cube center height above the sample.
- Physical camera PCB hole diameter and rear-component keepouts.
- Camera ribbon-cable exit direction and minimum bend clearance.
- Actual lens-to-camera assembled length at the working focus setting.
- Accessible top-face screw locations on the assembled uCube.
- Total mass and observed sag of the illumination cell.
- Desired accessory-rail standard and the maximum planned Köhler train length.
- Required clear aperture for future diaphragms, filters, and relay optics.

## First prototype boundary

Model only these pieces first:

1. One rear uFace adapter with a lower saddle, side registers, and tall post
   mounting tabs.
2. One horizontal camera extrusion joined to the post by opposed brackets or
   gussets.
3. One vertically adjustable camera plate, initially using either the
   four board holes or a captive tripod-foot cradle.
4. One removable illumination-rail datum aligned to the center of the active
   horizontal uCube face.

Do not redesign the beamsplitter face, M37 camera face, or illumination cell
until the shared-frame support is physically checked.

## As-built post_mount

Item 1 of the prototype boundary is modeled. `post_mount()` in
`optical_setup.scad`, exported as `exports/current/post_mount.scad`, with
`post_mount_socket_coupon` as its fit coupon.

### Geometry

| Quantity | Value | Where it comes from |
| --- | --- | --- |
| Overall envelope | 58.2 x 105 x 56.5 mm | Derived, not typed in |
| Enclosed volume | 120.63 cm^3 | Measured off the exported STL |
| Standoff, post face to cube center | 72 mm | Half of the 149.9 mm backlight short side, less a little |
| Backplate | 28.2 wide x 105 tall x 6 mm | Socket width and bolt access |
| Socket | 20.2 mm inner, 4 mm walls, 14 mm deep, 1.6 mm corner reliefs | 20 x 20 post plus 0.2 mm total clearance |
| M5 holes | Round, 5.5 mm, at Y +/-43 | Bolt-head access past the cube |
| M5 head approach | 11 mm pocket 3 mm deep, then a bell to a 24 mm mouth over 16.45 mm | Derived so a 9 mm driver has a straight run out through the gusset |
| M3 face screws | Pitch 26.0 mm, 6.0 mm cap reliefs bored 13.2 mm through the gusset | Pitch from the vendor formula, relief diameter from `capR = 3`, depth derived from the flare rate |
| Verified driver access | M3 clear to 6.0 mm, M5 clear to 9 mm | Swept-cylinder intersection against the bracket plus the 73 mm cube envelope |
| Gusset flare | 37.95 degrees over a 30 mm run | Asserted to stay inside the 45 degree overhang limit |
| Gusset windows | 3 circles, r 7 mm, 17 mm pitch, straddling the neutral axis | Mass and print time |

### Departures from the concept above

- **No saddle and no side cheeks.** The concept asked for a lower saddle and
  side registers. The cube face interface is the unmodified vendor uFace and
  nothing else, matching how the illumination cell mates. The four M3 face
  screws carry the load, as they already do for the cell. If the first article
  sags, the saddle is the first thing to add back.
- **One socket, not two saddles.** A single three-sided socket 14 mm deep
  captures the post across the full 105 mm of backplate, which does the same
  job as two separate saddles with fewer surfaces to print accurately.
- **Bolt access drives the plate height, not the cube.** This was not visible in
  the reference image. The T-nut sits in the post slot on the cube centerline,
  so both M5 heads face the cube and the 73 mm cube blocks them. Both holes are
  pushed out to Y +/-43 so the head and its washer clear the cube envelope by
  1 mm, and that clearance, not the cube, is what sets the 105 mm plate height.

### Further departures from the reference bracket

- **Round holes, not the reference bracket's pill slots.** The T-nut already
  slides freely along the post slot, so the bracket picks its own height when it
  is clamped. Slots would only spend plate material and add a stress riser at
  the most heavily loaded section to buy travel that already exists.
- **No coved root fillets.** The reference cove fills the inside corner of an L,
  where a horizontal plate meets a vertical one. Here the uFace and the
  backplate are parallel and 30 mm apart, so there is no corner. The flare is
  the cove. A concave arc between the same two endpoints, held inside the 45
  degree overhang budget, only scoops about 1.4 mm out of a 30 mm run.
- **The head bell opens through the outboard edge of the flare, and its height
  is derived, not chosen.** The bolt head faces the cube, so the hex key has to
  come back out through the gusset. The flare edge only recedes inboard of a
  9 mm driver at Z=-25.55, so the bell has to reach past that point. The first
  version used a typed-in 9 mm rise that stopped at Z=-31.5 and left a 2.7 mm
  shelf of gusset capping the funnel, which blocked even a 4 mm key. The rise is
  now computed from the flare rate and asserted. The bell never touches the
  critical section at the backplate junction, where the head pocket is still a
  plain 10 mm cylinder fully enclosed in material.
- **Fastener access is verified geometrically, not by eye.** A driver cylinder
  is swept along each access axis and intersected with the bracket plus the
  73 mm cube envelope. M3 face screws are clear to a 6.0 mm driver, which is the
  vendor cap counterbore diameter. M5 post bolts are clear to a 9 mm driver,
  held two full mm under the 11 mm funnel throat because the throat is a
  72-sided polygon and a nominally equal driver binds on facets.

- **The head pocket is sized for a washer, not just the head.** A bare M5 socket
  cap bears on 33 mm^2 of plate, which is 30 MPa at 1 kN of preload. A DIN 125
  washer spreads that over 55 mm^2, or 18 MPa. PLA creeps well below its yield
  stress under permanent load, so that margin is the difference between a joint
  that holds its alignment and one that has to be re-torqued. The washer OD is
  10.0 mm, but the throat is drawn as a 72-gon, so a nominal 10 measures 9.99
  across the flats and would not pass it. The pocket is 11.

- **Infill is not the strength lever on this part.** The gusset root has a
  section modulus of about 49,900 mm^3. The 5 N cell load on a 72 mm arm works
  it to 0.003 MPa, which is 0.01 percent of PLA interlayer strength, and models
  a 0.00007 mm tip deflection. So print it on the shared 0.4 mm profile as it
  stands, 15 percent grid and 3 perimeters, and add one solid modifier around the
  two M5 seats. What governs is local bearing and creep there, not the section.
  Sliced that way it is 69 g and 6h47m, of which about a seventh of the filament
  is buildplate-only support under the plate ledge. Raising infill to 20 percent
  gyroid and adding a fourth perimeter measures 82 g and 8h39m, which spends 13 g
  and two hours on a section already 4 orders of magnitude oversized.
  `led_post_slider` is a different case: a 3.8 g part with nothing structural in
  it, where infill only matters for giving the clamp-screw heat-set insert bite
  in the 6 mm harness wall. Its limit is heat, since v1 has no secondary
  heatsink.
- **The gusset root is masked by the vendor plate.** The gusset overlaps 0.5 mm
  into the uFace so the two slice as one solid, but inside that overlap it is a
  plain square slab. Unioned raw it re-filled the voids the vendor plate cuts
  for itself: the four mid-edge notches that clear the cube's retaining tabs,
  and the four corner cap counterbores. Neither defect shows up as a manifold
  error, so the export check passed the whole time. The weld band is now
  clipped to vendor face material and inset 0.1 mm inside the plate outline,
  and the boolean against the cube measures exactly empty. The inset matters on
  its own: the gusset is already flaring in Y by the time it reaches the band,
  so flush with the plate outline would stand 0.37 mm proud into the cube's
  0.4 mm face gap. The clip is written as one difference on one solid rather
  than two stacked pieces, because the stacked form duplicated a face across
  the whole gusset cross-section and OpenCSG preview z-fights on it.

### Still open

- Post slot opening width and T-nut thread are unconfirmed. M5 is assumed.
- The 0.2 mm total socket clearance is a first guess. Print the coupon first.
- Deflection and PLA creep are unmeasured. The bracket is permanently loaded in
  bending by the cantilevered illumination cell, which is the worst case for
  PLA. Prefer PETG.
- The camera still has no support of its own. Items 2 and 3 of the prototype
  boundary are not designed.

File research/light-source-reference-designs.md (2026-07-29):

# Compact uniform square light for the 50 mm beamsplitter cube

Research only. This note does not select or modify the final CAD design. The
remaining design questions must be resolved first.

## Provisional conclusion

Keep the light's output window nearly flush with the cube's inside face. Put
the LEDs, optical mixing volume, wiring, and aluminum heat path outside the
cube. This preserves the volume required by the 45-degree beamsplitter.

```text
outside cube                                      inside cube
[heat spreader | LEDs | mixing optics] -> [diffuser/output]  gap  / 45-degree plate
                                                        cube face |
```

There are two strong implementations:

1. **Best first prototype:** a direct-lit 6 x 6 or 7 x 7 wide-angle LED array,
   shallow reflective cavity, and replaceable diffuser. It is easy to build,
   measure, and tune.
2. **Best thin final cassette:** a patterned edge-lit light-guide plate with a
   rear reflector and top diffuser. Complete 50 mm commercial precedents are
   6 to 8.5 mm thick, but good uniformity requires a graded extraction pattern
   and a non-emitting mixing border near the LED rail.

An off-the-shelf backlight mounted outside a face is the fastest way to test
whether this illumination concept works before designing either cassette.

The first unresolved decision is more important than the LED choice: define
where the light must be uniform. A uniform glowing panel does not guarantee
uniform irradiance after the beamsplitter or in the final camera image.

## Focused 30 mm output result

This section assumes a 30 mm circular or square output and only 15 to 20 mm of
total optical depth outside the cube face.

**Result:** no verified stock design found here gives a full 30 mm square,
strong collimation, good spatial uniformity, and a 15 to 20 mm total depth.
The best first build is one shallow backlight with swappable front optics:

1. **Diffuse mode:** opal diffuser only. This prioritizes an even glowing face.
2. **Semi-collimated mode:** the same diffuser plus two crossed 3M brightness
   enhancement films. This narrows the output in both axes but is not true
   collimation.
3. **Optional directional coupon:** replace the diffuse source with a small LED
   and a compact TIR or Fresnel optic. This tests directionality, but it is a
   different source cartridge and will not produce the same uniform glowing
   face.

### Why one short lens cannot do both jobs

[Edmund Optics](https://www.edmundoptics.com/knowledge-center/application-notes/optics/considerations-in-collimation/)
states that ideal collimation requires an infinitesimal source at the lens
focus. Every point on an extended diffuser sends out a parallel bundle at a
different angle. Approximate full angular span is:

`full angle = 2 atan(source width / (2 focal length))`

For a 30 mm diffuser, the result is about 81 degrees with a 17.5 mm focal
length and 64 degrees with a 24 mm focal length. Reaching a 15-degree full
angle would require about 114 mm focal length, before lens thickness.
[Thorlabs](https://www.thorlabs.com/newgrouppage9.cfm?objectgroup_id=2692&partnumber=MWWHLP2)
also notes that LED size, focal length, and numerical aperture set the remaining
divergence.

This is the key distinction:

- A small LED die behind a 30 mm lens can make a roughly 30 mm directional beam.
- A 30 mm glowing diffuser cannot be turned into a narrow beam by one short
  lens.

[ams OSRAM's etendue guide](https://look.ams-osram.com/m/7b830a12bd3b7cfb/original/Projection-with-LED-light-sources.pdf)
explains the deeper limit: passive optics cannot reduce source area and angular
spread together without discarding light.

### Compact option comparison

| Option | What it actually solves | Depth result | Decision |
|---|---|---:|---|
| [3M crossed BEF prism films](https://multimedia.3m.com/mws/media/1389247O/application-guide-for-bef-family.pdf) | Compresses a diffuse backlight's angular output in both axes | About 0.31 mm for two 155 micrometer sheets, excluding supports | Best swappable semi-collimated prototype |
| [Opto Engineering CLLT film](https://www.opto-e.com/en/products/CLLT-series/CLLT3BC050050) | Published 15 +/-5-degree output from its matching backlight | 3.7 mm | Strong quantified precedent. Ask whether a 30 mm custom size is available |
| [LEDiL OLGA](https://www.ledil.com/news_all/product-news-olga/) | Collimates a small LED into a 10, 20, or 41-degree round beam | 30 mm diameter x 18.5 mm high | Fits depth narrowly. Directional cartridge only, not a uniform 30 mm square face |
| [Fresnel Technologies lens 0.3](https://www.fresneltech.com/hubfs/Spec%20Sheets/Fresnel%20Lens%20Brochure.pdf) | Thin point-source collimator | About 16.5 mm source-to-front | Fits, but active area is only 25 mm. Useful proof, not the final 30 mm output |
| 30 mm molded asphere | Better point-source collimation than a PCX lens | About 24 to 30 mm source-to-front for checked stock parts | Does not fit 20 mm and clear apertures are only 24 to 28 mm |
| Fly-eye or microlens system | Homogenizes a defined target plane | Normally needs two arrays plus a field lens | Stock 30 mm-class systems do not fit |
| Square light pipe | Mixes spatial nonuniformity, not angle | Stock examples are much longer than 20 mm | Reject for this envelope |
| Complete coaxial or telecentric light | Finished uniform directional illumination | Closest units checked are 33 to 125 mm deep | Reject as a component. Copy only the optical architecture |

Two geometry traps matter:

- A 30 mm diameter circular lens does not cover a 30 x 30 mm square. Covering
  the square corners requires at least a 42.4 mm circular clear aperture.
- A thin Fresnel sheet does not remove the source-size limit. It only reduces
  lens thickness.

### Recommended swappable prototype

```text
outside                                                     cube interior
[aluminum spreader | LED PCB | white 6-8 mm mixing cavity]
                  -> [opal diffuser] -> [swappable front film] -> 30 mm aperture

front D: no prism film                     diffuse, widest angle
front C1: one BEF sheet                    narrowed in one axis
front C2: two BEF sheets crossed 90 deg    narrowed in both axes
```

Start with a 5 x 5 wide-angle LED array near 6 mm pitch, a reflective cavity,
and a 30 x 30 mm output mask. Put the output nearly flush with the inner face.
This stays within the earlier direct-lit guidance while leaving the
beamsplitter volume clear. On 3M BEF, the prisms face away from the backlight.

Do not place a TIR or Fresnel optic after the diffuser and call the result
collimated. The directional test must replace the extended diffuser source with
a small LED near the optic's focus.

Before CAD, test fronts D, C1, and C2 without moving the source. Use fixed
camera exposure and measure both:

- spatial uniformity over the intended 30 mm region after the beamsplitter;
- beam growth on a screen at two distances, using
  `full angle = 2 atan((D2 - D1) / (2 distance change))`.

This experiment determines whether semi-collimation improves the real image
enough to justify its lost brightness and possible prism texture.

## Critical geometry from the current CAD

**Correction:** the earlier 52 mm interior interpretation is superseded. Direct
measurement of `exports/microcube-base.stl` and the official library default
`CubeSize(size=40, d=7)` establish the controlling envelope below.

- Clear internal span: 40 mm.
- Cube face: 54 mm.
- Overall cube envelope: 68 mm.
- Beamsplitter: 50 x 50 x 2.05 mm.
- Beamsplitter orientation: vertical and 45 degrees in plan view.

Engineering consequences:

- A 50 mm emitting area cannot pass through the 40 mm clear span. A complete
  50 mm-class light or its housing must remain outside the cube and illuminate
  through a smaller face aperture.
- A 50 mm plate at 45 degrees presents only this width to a face-normal,
  collimated beam:

  `W_projected = 50 cos(45 degrees) = 35.36 mm`

- A 30 mm face-normal field fits within that 35.36 mm projection with about
  2.68 mm nominal margin per side. If the plate has only 45 mm clear aperture,
  the projected width becomes 31.82 mm and the margin falls to 0.91 mm per
  side. The beamsplitter's actual clear aperture must be verified.

- A 50 mm-wide folded collimated field would require a plate about
  `50 / cos(45 degrees) = 70.71 mm` wide, before clear-aperture margins.
- The plate endpoints are only
  `40/2 - 25 cos(45 degrees) = 2.32 mm` from the adjacent inside faces. Keep the
  source output essentially flush. Even a small inward-projecting retainer can
  collide with the beamsplitter edge.
- A 61 x 61 mm external module is smaller than the 68 mm overall cube envelope
  but larger than the 54 mm face. It still needs an external holder or revised
  face attachment, not an assumed internal or flush fit.

The 35.36 mm result applies to face-normal rays. A diffuse source contains many
ray angles, but light outside the plate's projected aperture still cannot be
cleanly folded into the intended axis. The needed field must be clarified.

## "Perfectly even" needs a metric

No physical source is perfectly uniform. Specify all four items:

1. Measurement plane: emitting window, target/object, or raw camera image.
2. Region of interest, for example the central 32 x 32 mm.
3. Metric, for example peak deviation, coefficient of variation, or min/max.
4. Operating state: wavelength, brightness, warm-up time, continuous or strobe.

Useful definitions are:

- `peak deviation = max(abs(E - mean(E))) / mean(E)`
- `CV = standard deviation(E) / mean(E)`
- `min/max = E_min / E_max`

[Labsphere's uniform-source guide](https://labsphere.com/wp-content/uploads/2021/09/Integrating-Sphere-Uniform-Source-Applications.pdf)
emphasizes that radiance uniformity at the source and irradiance uniformity at
a target are different measurements, and that target distance and geometry
affect irradiance uniformity.

## Architecture comparison

| Architecture | Strength | Main problem here | Provisional use |
|---|---|---|---|
| Direct LED array + diffuser cavity | Cheapest and easiest to tune | Needs optical depth and thermal testing | Best first custom prototype, with the cavity outside |
| Patterned edge-lit guide | Thin, low power, even emitting plane | Good extraction pattern is difficult to DIY; needs a mixing border | Best thin final cassette or OEM route |
| Complete commercial backlight | Known performance and fast test | All 50 mm-class housings exceed the 40 mm interior | Mount outside a face for concept validation |
| Shallow integrating cavity | Broad, diffuse angular output | A 50 mm exit consumes too much cavity volume | Reject as the first cube design |
| Integrating sphere | Calibration-grade radiance uniformity | Far too large | Performance reference only |
| Koehler illumination | Can homogenize the object plane | Adds collector, stops, condenser, length, and alignment | Only if final target-plane tests demand it |
| Collimated/telecentric backlight | Directional rays for measurement | Larger and more expensive; may be the wrong contrast | Only for metrology or directional imaging |

### Direct-lit design guidance

Two primary-source rules bracket the first experiment:

- [Nichia's 2025 direct-lit design note](https://led-ld.nichia.co.jp/api/data/spec/tech/SP-QR-C2-240141-E_Design%20Considerations%20for%20the%20Nichia%20NFSWL11A-D6%20LED.pdf)
  reports acceptable uniformity with wide-directivity LEDs at optical
  distance/LED pitch ratios around 0.7 to 0.8 in its tested construction. The
  test used reflective white solder mask and a 2 mm opal diffuser.
- [Luminit's hotspot application note](https://www.luminitco.com/sites/default/files/AppNote1_Hotspots_6_4_12_lo.pdf)
  gives the more conservative rule that diffuser distance should be at least
  the LED spacing. High-angle diffusers can help when this is not possible.

Inference for a first coupon, not a final design: a 6 x 6 or 7 x 7 array over a
roughly 42 to 48 mm square gives 7 to 8 mm pitch. Start with 6 to 8 mm of mixing
depth outside the face and test multiple diffusers. This stays near both source
rules without consuming beamsplitter space.

[Luminit](https://www.luminitco.com/sites/default/files/2022-07/Luminit_MachineVison_Tech-Data_0722_web.pdf)
publishes 85% to 92% transmission for its light-shaping diffuser family, so
greater hiding power trades away some brightness.

### Edge-lit design guidance

[ams OSRAM's light-guide design note](https://look.ams-osram.com/m/1c69505c886141ed/original/Light-guides.pdf)
shows that a uniform edge-lit guide needs:

- a non-active mixing range beside the LEDs;
- graded extraction dots or roughness, not an unmodified clear acrylic sheet;
- a rear reflector; and
- usually a top diffuser.

Therefore, a plain laser-cut acrylic square plus an LED strip should not be
assumed uniform. The LED rail and mixing border should live in the external
face flange, leaving only the selected output aperture near the 40 mm opening.

### Why a true integrating sphere is not compact enough

[Labsphere's integrating-sphere theory guide](https://www.labsphere.com/wp-content/uploads/2021/09/Integrating-Sphere-Theory-and-Applications.pdf)
recommends keeping total port area to a small fraction of sphere area. Using a
5% port fraction as a sizing check, a 50 x 50 mm port alone implies a sphere
diameter of about `sqrt(2500/(0.05 pi)) = 126 mm`, before other ports. That does
not fit either the 40 mm interior or the 68 mm overall cube envelope.

For a shallow reflective cavity, a high-diffuse-reflectance lining is more
appropriate than printed plastic alone. Furukawa reports [MCPET total
reflectance above 99% and diffuse reflectance above 96%](https://www.furukawaelectric.com/en/platform/brightening-mcpet.html).
This is a material reference, not a claim that a shallow cavity becomes an
integrating sphere.

## Beamsplitter consequences

- [Edmund Optics](https://www.edmundoptics.com/knowledge-center/application-notes/optics/what-are-beamsplitters/)
  notes that plate beamsplitters are commonly designed for 45-degree incidence
  and can add transmitted-beam shift, rear-surface ghost reflections,
  wavelength dependence, and polarization dependence. The exact plate and
  coating orientation therefore matter.
- For a path that reflects once and transmits once through an ideal 50/50
  splitter, the upper-bound splitter efficiency is `R x T = 0.25`, before all
  other losses. [CCS's coaxial-light architecture](https://www.ccs-grp.com/products/series/245)
  is a relevant commercial precedent for this double interaction.
- Using Snell's law with an assumed refractive index of 1.5, the 2.05 mm plate
  gives about 0.68 mm transmitted-ray lateral shift at 45 degrees. This is an
  inference until the actual glass index is known.

## Thermal constraint

The printed face should locate optics, not serve as the primary LED heat sink.
[Cree LED's thermal guide](https://assets.cree-led.com/a/da/x/XLamp-Thermal-Management.pdf)
describes the heat path from LED junction through PCB and thermal interface to
a heat sink and ambient. Put a metal-core PCB or aluminum spreader outside the
cube, then verify case and printed-part temperatures at steady state.

## Compact comparison

`Not stated` means the manufacturer does not publish that value in the cited page or datasheet. Inferences are labeled.

| Reference | Emitting area | Complete size | Published uniformity | Working distance | Electrical / heat | Availability / customization | Fit assessment |
|---|---:|---:|---:|---|---|---|---|
| [PHLOX LEDW-BL-50x50-LLUB](https://www.phlox-gc.com/datasheet/PHLOX_LEDW_BL_50x50_LLUB_Q_1R_24V.pdf) | 50 x 50 mm | 90 x 85 x 8.5 mm | >=95% (manufacturer notation also says +/-10%) | Not stated, specified at emitting surface | 24 V, <=260 mA, inferred <=6.24 W; housing may reach 80 C and must not be covered | Standard 50 mm size; PHLOX also advertises custom sizes up to 500 mm | Excellent uniformity/thickness reference, too large as a complete insert |
| [CCS LFL-50SW2-IU](https://www.ccs-grp.com/products/model/3151) | 50 x 50 mm | 72 x 72 x 6 mm | Numeric value not stated; series publishes a representative plot | Not stated, flat emitting surface | 24 V, 3.6 W max, natural cooling | Standard/on sale; CCS invites custom inquiries for the LFL series | Thinnest complete standard module found, but 20 mm too wide for cube interior |
| [TPL Vision SBACKII050502](https://www.tpl-vision.com/documents/techsheets/TPL_SBACK_II_TechSheet_FR.pdf) | 51 x 51 mm | 61 x 61 x 20 mm | [>90% surface uniformity](https://www.tpl-vision.com/overview/accessories/mounting-devices/tpl-mount-sback-square1/) | Not stated; 52 klux measured on diffuser surface | 24 V, 3 W max, aluminum body | Standard configured product, CAD available | Best compact complete module. Smaller than the 68 mm overall envelope, but larger than the 54 mm face and 40 mm clearance. Mount externally behind a face aperture |
| [TPL Vision CSBACK 50 x 50](https://www.tpl-vision.com/documents/technotes/TPL_Collimated_Lightings_Tech_Note_EN.pdf) | 50 x 50 mm nominal minimum | Outer length/width not stated; 21 mm thick | 90% surface homogeneity, qualified for telecentric viewing | Not stated | 24 V; power not stated | Configurable from 50 to 200 mm in 50 mm steps | Useful if directional output matters; ordinary diffuse backlight is likely simpler unless the imaging path needs collimation |
| [Opto Engineering LT3BC050050-W](https://www.opto-e.com/en/products/LT3BC-series/LT3BC050050-W) | 50 x 50 mm | 58 x 76 x 24 mm | Called excellent; numeric value not stated, individual measured test report advertised | Emitting-surface specification | 24 V, 140 mA, 3.4 W continuous; 6.7 W boost | Standard current product, optional collimation/polarization; manufacturer says contact for customization | Narrow dimension is close, but 76 mm length prevents internal fit. Good low-power optical benchmark |
| [Advanced Illumination BX2-00500050](https://www.advancedillumination.com/wp-content/uploads/2024/11/BX2_Series_Datasheet.pdf) | Ordering size 50 x 50 mm; drawing implies actual window 48.5 x 48.5 mm | Inferred from drawing: about 105.9 x 105.9 x 19.0 mm | +/-10% for emitting lengths below 200 mm | Uniformity measured at emitting surface | 24 V; white voltage-drive configuration is 0.30 A for 50 mm illuminated length, inferred 7.2 W | Built to order, typical 1 to 2 week shipment; 25 mm increments; semi/full custom advertised | Strong documented optical benchmark, far too large mechanically |
| [Metaphase TXBL/TXCBL](https://www.metaphase-tech.com/tx-backlight/) | 50 x 50 mm minimum | 10 mm bezel, other dimensions in downloadable drawing; exact 50 mm overall size not extracted | Not stated | Not stated | 24 V controller ecosystem; power not stated | Current configurable family; quick-ship options by inquiry; white/R/G/B/RGB/RGBW/IR, polarizer and collimated versions | Broadly configurable reference, but 10 mm bezel implies roughly 70 x 70 mm overall, an inference |
| [CCS LFV3-50 coaxial light](https://www.ccs-grp.com/products/model/4299) | Internal light-emitting surface 52 x 52 mm | 60 x 94 x 58 mm | Numeric value not stated; optional darker diffuser is documented to increase uniformity | Manufacturer example uses 57 mm LWD and 63 x 47 mm FOV in the [LFV3 note](https://www.ccs-grp.com/ecsuites/media/download/pamphlet/FL_LFV3_e.pdf) | 24 V; 11 W max for white | Standard family plus custom 90-degree port version | Best architecture precedent because it integrates square source, diffuser, and 45-degree half-mirror. Too large to reuse directly |
| [Fusion Optix custom MicroTEK light guide](https://www.fusionoptix.com/solutions/dna/lcd-backlighting/) | Custom; no 50 mm standard listed | Standard guide thicknesses 0.5, 1, 2, 4, 6 mm; LED rail and films add size | >90% 9-point uniformity standard; up to 90% optical efficiency | Not stated, output is the guide surface | Depends on custom LED rail/driver | Explicit system-level customization; components or complete backlight unit | Best OEM path for a custom 30 mm output through the 40 mm opening because guide, extraction pattern, LED rail, and films can be tailored together |
| [Labsphere MiniStar MS12-25BB](https://www.labsphere.com/product/ministar-uniform-illuminator/) | 12 mm circular exit | 25 mm square footprint; depth not stated | Qualitatively uniform, numeric value not stated | Not stated | Not stated | Current product; additional spectral variants prioritized by demand | Integrating-cavity precedent only. Its aperture is much too small, and scaling an integrating cavity to 50 mm would consume cube volume |

PHLOX's datasheet combines `>=95%` and `+/-10%` without publishing the exact
calculation. Treat it as a vendor benchmark until a measurement map and metric
are reviewed. The same caution applies to any unlabeled "uniformity" number.

## Best examples to copy

### 1. Nichia direct-lit test construction

Nichia's test setup combines wide-angle LEDs, reflective white solder mask,
and a 2 mm opal diffuser, then maps uniformity against LED pitch and optical
distance. Copy the experimental method, not its exact LED count. Source:
[Nichia design note](https://led-ld.nichia.co.jp/api/data/spec/tech/SP-QR-C2-240141-E_Design%20Considerations%20for%20the%20Nichia%20NFSWL11A-D6%20LED.pdf).

### 2. CCS LFL edge-lit construction

CCS places LEDs around a square light-guiding diffusion plate. Its special extraction pattern produces a flat diffuse source, and the 50 mm model is only 6 mm thick. This is the closest physical architecture to copy into a custom face cassette. Source: [CCS LFL series](https://www.ccs-grp.com/products/series/14).

### 3. PHLOX 50 mm performance target

PHLOX publishes >=95% uniformity and >=100,000 cd/m2 continuous luminance for a 50 x 50 mm, 8.5 mm-thick edge-lit source. The complete housing is too large, but it is a useful high-end benchmark. Source: [PHLOX datasheet](https://www.phlox-gc.com/datasheet/PHLOX_LEDW_BL_50x50_LLUB_Q_1R_24V.pdf).

### 4. TPL SBACK II external cartridge

At 61 x 61 x 20 mm with a 51 x 51 mm useful surface, this is the most plausible off-the-shelf module to mount behind a custom cube face. It also has the lowest published power among the complete 50 mm-class sources here at 3 W. Source: [TPL datasheet](https://www.tpl-vision.com/documents/techsheets/TPL_SBACK_II_TechSheet_FR.pdf).

### 5. CCS LFV3 integrated beamsplitter layout

The LFV3 is a direct precedent for placing a square LED/diffuser source next to a 45-degree half-mirror. It proves the architecture, while also showing why a 50 mm field is mechanically tight: its commercial housing is 60 x 94 x 58 mm. Source: [CCS LFV3 product](https://www.ccs-grp.com/products/model/4299) and [application pamphlet](https://www.ccs-grp.com/ecsuites/media/download/pamphlet/FL_LFV3_e.pdf).

### 6. Fusion Optix custom thin guide stack

Fusion Optix publishes >90% nine-point uniformity and lists 0.5 to 6 mm guide thicknesses, plus matching LED rails and optical films. This is the best documented custom/OEM route when the 40 mm clear span is non-negotiable. Source: [Fusion Optix LCD backlighting](https://www.fusionoptix.com/solutions/dna/lcd-backlighting/).

## Missing context that changes the choice

- Is this illumination for a camera, a viewer's eye, or a projected pattern?
- Required spectrum: white CCT/CRI, monochrome wavelength, IR, or RGB?
- Required brightness at the target or camera exposure, and continuous versus strobed operation?
- Maximum allowed source thickness outside the cube face?
- Must the output optic fit through the 40 mm opening, or may the complete
  housing sit outside the 54 mm face and within or beyond the 68 mm envelope?
- Required useful illuminated square: full 50 x 50 mm, or a smaller central field?
- Required uniformity definition and threshold, for example min/max over 9 points or +/- variation?
- Desired angular output: diffuse Lambertian-like, semi-collimated, or telecentric-compatible?
- Beamsplitter coating ratio and wavelength range, which determine how much light is lost and whether polarization matters?
- Heat limit near the printed material and whether an aluminum heat spreader is acceptable?

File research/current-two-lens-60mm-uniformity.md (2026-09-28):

# Current illumination: broad field, flat correction, and next bench tests

Date: 2026-09-28. Status: research and test plan, not an optical prescription.

## Decision

Start with the 150 mm lens removed. The latest physical A/B test reports a
broad field with only a side-to-side gradient in that configuration. Keep the
existing collector, establish measured coverage and edge signal, then test
flat-field correction before adding optics.

The objective is reliable corrected block images. Perfect physical uniformity
is not required if stable shading can be corrected without losing useful
signal. "Works 99% of the time" remains a target, not a measured result.

## Evidence and limits

Labels below distinguish the basis of each statement:

- **Reported fact:** supplied by the user from the physical setup, not
  independently measured in this research pass.
- **Repository fact:** verified in the current project source or design record.
- **Calculation:** derived from stated assumptions; it is not a measurement.
- **Inference:** a plausible explanation or design choice to test.
- **Unknown:** data needed before a final design decision.

| Item | Evidence |
| --- | --- |
| Source | **Reported fact:** nominal 3 W white 3535 LED, approximately 3.5 mm dome and 120 degree emission specification. Dome/package size does not establish emitting-area size; nominal electrical power does not establish optical power. |
| Collector | **Reported fact:** approximately 40 mm diameter, spherical, focal length estimated near 18 mm. Exact geometry and focal data are unknown. |
| Second lens | **Reported fact:** approximately 40 mm diameter, aspheric, focal length estimated near 150 mm; approximately 180 mm from this lens to the block. Whether that distance follows the folded light path needs confirmation. |
| Earlier behavior | **Reported fact:** central hotspot with two lenses; diffuser trials did not provide sufficient useful field; a configuration described as Kohler-like gave an approximately 25 mm even spot. |
| Latest A/B test | **Reported fact:** removing the 150 mm lens produced a broad field with only a side gradient. The useful field diameter, gradient magnitude, exposure, and edge noise have not yet been recorded here. This does not yet prove a usable 60 mm field. |
| Object | **Reported fact:** block roughly 25 x 40 mm; desired field perhaps 60 mm diameter. Position and height tolerances remain undefined. |
| Apertures | **Repository fact:** `optical_setup.scad` sets a 40 mm cell port, 38 mm carrier aperture, 45 mm cube opening, and a 50 x 50 mm beamsplitter at 45 degrees. Verify the actual installed configuration. |
| Old prescription | **Repository fact:** `DESIGN.md` section 9 and a source comment assume 16/40 mm focal lengths and 56 mm lens separation. Those assumptions do not describe the current estimated 18/150 mm optics. No source or design parameters were changed by this note. |

**Inference:** the latest A/B result makes the second lens the first component
to leave out. It implicates that lens's role in the tested layout, not a defect
in the lens or proof that every condenser is unsuitable.

## What the geometry does and does not imply

**Calculation:** a centered 25 x 40 mm rectangle needs a circular field of at
least `sqrt(25^2 + 40^2) = 47.2 mm` to cover its corners. A 60 mm target adds
placement margin; determine whether that margin is actually needed.

**Calculation:** a 50 mm plate at 45 degrees presents approximately
`50 cos(45 degrees) = 35.4 mm` in one projected direction, before mounting or
coating margins. Together with the 38 mm carrier aperture, this rules out a
60 mm parallel beam through the present assembly. It does **not** rule out a
60 mm expanding field at the more distant object plane.

**Calculation, ideal thin-lens model:** if the LED is one focal length before
the first lens, the lenses are separated by `f1 + f2`, and the target is one
focal length after the second lens, the system images the LED at magnification
`f2 / f1 = 150 / 18 = 8.3`. An apparent 3 mm emitter would become a 25 mm image.
That makes source imaging a possible explanation of the earlier spot. The
actual emitter size, lens geometry, and spacings are unknown, so this is not a
diagnosis of the bench setup.

**Primary-source principle:** Kohler illumination requires two distinct
mappings: the source is imaged into an aperture plane, while a field stop is
imaged onto the specimen. Two positive lenses at `f1 + f2` spacing do not by
themselves establish those mappings. [Nikon: conjugate planes](https://www.microscopyu.com/microscopy-basics/conjugate-planes-in-optical-microscopy)

**Calculation, ideal thin-lens model:** a 150 mm lens forming an image at
180 mm requires an object distance of 900 mm and gives 0.2x magnification.
It is therefore not a straightforward choice for magnifying a nearby small
uniform source onto this block plane. Principal-plane locations and the other
lens alter the complete system, so this is a design screen rather than a
spacing instruction.

**Calculation:** spreading unchanged captured flux from a 25 mm circle to a
60 mm circle reduces average irradiance to `(25 / 60)^2 = 0.174`, about 17%.
Coverage, brightness and angular spread must be considered together. Extended
sources also retain divergence after collimation. [Edmund: collimation](https://www.edmundoptics.com/knowledge-center/application-notes/optics/considerations-in-collimation/)

## Cost-ranked architecture ladder

This is an order for experiments, not verified pricing or a shopping list.
Reprints and changes to existing parts come first. No purchases are proposed
until the cheaper measurements show what is missing.

| Priority | Architecture or change | Why try it | Evidence required before moving on |
| --- | --- | --- | --- |
| 1, existing parts/reprints | Remove the 150 mm lens; center and reposition the LED/collector; adjust or reprint holders only if the physical mount prevents alignment | The reported A/B test already gives a broad field; the remaining gradient may be correctable | Measured ROI coverage, unsaturated center, usable edge signal, repeated gradient map |
| 2, existing camera/software | Dark subtraction and a separate flat correction for each fixed illumination state | Corrects repeatable shading without adding optical parts | Corrected matte-reference residuals and real-block performance across allowed positions/heights |
| 3, inexpensive optical experiment | Crossed source and camera polarizers | Direct test of whether the troublesome bright regions are polarized glare | Exposure-normalized comparison, remaining tissue contrast, wax/plastic artifacts, edge signal |
| 4, small source/mount change | Alternate two laterally offset LEDs or first reposition the same LED for A/B captures | Tests whether different angles provide complementary usable views | Full coverage for each state, separate flats, stable registration, evidence that one frame rescues regions lost in the other |
| 5, larger printable light engine | Diffuse panel or reflective mixing cavity feeding the existing beamsplitter | Creates an extended luminous source when the single emitter remains too sensitive | Target-plane uniformity and real-block contrast at the required working distance; aperture compatibility |
| 6, specialty optics, roughly $150 budget class | Homogenizing rod/array plus a designed relay, or a purpose-selected condenser/illumination module | Appropriate only if measured field or angular requirements defeat simpler options | Actual prescription, clear apertures, working distance, throughput and an explicit acceptance test before purchase |

The last row is a spending tier, **not a current product quote**. A specialty
part alone does not guarantee a complete uniform illumination system.

**Primary-source precedent:** CCS coaxial lights combine an LED array,
adjustable diffusion plate and half mirror. The diffuser's position and
transmission affect the illumination. [CCS LFV3 architecture](https://www.ccs-grp.com/products/series/150)

**Primary-source precedent:** a light pipe mixes illumination through internal
reflections. Its output still needs a suitable projection or coupling system.
[Edmund: light pipes](https://www.edmundoptics.com/knowledge-center/video/tutorials/light-pipe-overview/)

## Flat correction: what it can recover

**Primary-source principle:** flat correction compensates repeatable sensor
response variation and illumination/lens shading.
[Basler: flat-field correction](https://docs.baslerweb.com/flat-field-correction)

| Usually suitable for flat correction | Requires another remedy or a rejected capture |
| --- | --- |
| Smooth gradient fixed relative to the camera | Saturated glare: clipped detail is missing |
| Stable optical vignetting with adequate signal | Dark edges where noise dominates the wanted signal |
| Repeatable per-channel response | Highlights or shadows that move with block position or tilt |
| Stable differences between LED states, using a flat for each | Sample-dependent additive flare or changes after optics move |

**Model:** for linear image `I`, averaged dark frame `D`, and averaged flat
`F`, a basic correction is `(I - D) / (F - D)` times a chosen normalization.
Mask invalid or near-zero denominators; do not present amplified noise as
recovered detail. The flat target must have uniform reflectance, fill the ROI,
and sit at the relevant block height. Paper is useful for an initial comparison
but its texture and nonuniformity should not become the calibration pattern.

**Unknown:** fixed AE/AWB-off capture settings help repeatability but do not
establish a linear image pipeline. Confirm raw or otherwise linear data,
black-level handling, exposure, gain, lens aperture and existing shading
correction before judging a numerical correction.

## Two alternating LEDs: useful hypothesis, separate test

**Inference:** two angles can provide complementary views of specular glare.
They do not replace coverage or per-state flat correction.

- Move the source **across** the optical axis in the same source plane to
  test direction changes. Moving it **along** the axis mainly changes focus
  and cone width. "Different heights" changes angle only when height is
  transverse to light propagation in that part of the system.
- **Calculation, simple collimator only:** 1 mm lateral offset at an 18 mm
  focal length corresponds to approximately `1 / 18 rad = 3.2 degrees`.
  The full optical train determines the actual block illumination angle.
- **Inference from an ideal matte-surface model:** averaging equal opposite
  angles can cancel one component of slope shading. Shadows, specular
  highlights and other surface effects remain.
- Preserve A and B separately. Normalize each with its own flat and check
  registration. A blind pixelwise minimum can select shadows and noise;
  averaging does not remove a highlight present in one frame. Test selection
  or weighted fusion only where at least one frame contains usable signal.
- If both frames clip or both lose the same region in darkness, fusion cannot
  recover it. Do not claim a general texture-free reflectance image from two
  views.

**Primary-source principle:** crossed source/camera polarizers can suppress
specular hotspots, but reduce throughput and can reveal polarization changes
in stressed transparent material. Compare this with angle diversity using
matched exposure and real blocks. [Edmund: polarization techniques](https://www.edmundoptics.com/knowledge-center/application-notes/illumination/successful-light-polarization-techniques)

## Decision tree

```mermaid
flowchart TD
    A[150 mm lens removed] --> B{Required ROI has usable unclipped signal?}
    B -->|No| C[Measure clipping and reposition existing parts]
    C --> D{Coverage still insufficient?}
    D -->|Yes| E[Diffuse light engine or designed relay]
    D -->|No| F[Measure repeatability]
    B -->|Yes| F
    F --> G{Gradient stable across allowed conditions?}
    G -->|Yes| H[Apply per-state flat correction and validate]
    G -->|No| I{Artifact follows block surface or tilt?}
    I -->|Yes| J[Compare crossed polarization and two angles]
    I -->|No| K[Resolve alignment drift or stray light]
```

## Bench-return checklist

- [ ] **Define success:** select the actual ROI, permitted placement and
  height range, maximum exposure and a failure criterion. Define what the
  requested 99% success rate counts before testing it.
- [ ] **Record geometry:** photograph the current arrangement with a ruler;
  record source-to-collector, collector-to-second-lens when present,
  last-lens-to-splitter and splitter-to-block distances. Mark lens orientations
  and carrier positions. Confirm whether the stated 180 mm follows the folded
  light path.
- [ ] **Repeat the key A/B:** hold LED current, camera settings, block plane
  and remaining optics fixed; capture second lens installed and removed.
  Record field width in millimeters, center/edge levels and clipped pixels.
- [ ] **Separate lighting from surface response:** capture a dark frame, a
  matte reference at block height, then a glossy real block. A hotspot only on
  the block points toward surface-dependent glare rather than simple shading.
- [ ] **Test correction stability:** capture the reference at the intended
  center/corner positions and minimum/maximum heights; repeat after warm-up.
  Plot a brightness map and horizontal/vertical profiles before and after
  correction. Record residual variation and repeat noise.
- [ ] **Test real specimens:** include pale tissue, dark tissue, smooth wax,
  scratched wax and glossy cases. Repeat controlled positions and small tilts.
  Evaluate retained tissue boundaries and contrast, not only a flatter image.
- [ ] **Try angle/polarization changes only when indicated:** first move one
  source for sequential A/B tests if practical; then decide whether a second
  LED is justified. Keep separate originals and flats for each state.
- [ ] **Choose the next change from the measured failure:** alignment for a
  gradient, exposure/throughput for weak edges, glare control for surface
  reflections, and a new light engine only for persistent coverage or angular
  limitations. Optical success requires these bench results; CAD fit alone
  does not establish it.

## Open requirements

The final architecture still depends on the useful field and placement margin,
the angular distribution needed for tissue contrast, actual lens prescriptions,
the splitter's clear coated aperture, allowable exposure and duty cycle,
temperature stability, and whether one calibration survives the permitted block
height and tilt range. Uniform appearance on a matte reference does not alone
establish uniform appearance on wax.

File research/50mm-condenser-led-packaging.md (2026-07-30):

# 50 mm condenser, LED, driver, and heatsink packaging

## Supplied collimator update, 2026-07-29

The selected hardware is now a two-lens collimator cartridge with a spacer
ring, not the provisional bare 50 mm asphere studied below. Measurements
supplied from the physical assembly are:

- 41 mm outside diameter;
- 24.1 mm assembly thickness along the light-propagation path;
- slight bevel on the front lens;
- a later rough sketch confirms `a = 1 mm` groove inset, `b = 3 mm` end-lip
  thickness, and 30 mm complete housing depth;
- its separate C-shaped feature is a flat retaining spring with an approximately
  15 mm opening and a measured compressed diameter of about 37.44 mm;
- a physical reference photo shows the spring sharing the same cylindrical bore
  behind the lens stack rather than occupying a separate snap-ring groove;
- the spring wire diameter is 1.04 mm and its bent form is intentional, so it must
  not be used as the radial locator or press directly against a lens surface;
- the rear ring compresses the spring axially to preload the lens against the
  front stop through a flat annular pressure washer. The spring's compressed
  axial height remains unknown.

These two measured envelope dimensions supersede the old 50 mm mechanical CAD
defaults. Clear aperture, focal length, lens-element spacing, and spring
compression remain unknown and provisional. The older research below is kept
as design history for the LED, driver, and thermal packaging decisions.

Scope: mechanical packaging guidance for the existing official 40 mm uCube
light face. This does not change `optical_setup.scad`.

## Recommendation

Build this as an **external, removable light engine**, not as parts inside the
cube or the current 48 mm chamber:

```text
cube <- 30 mm aperture <- curved condenser face | condenser | plano face
     <- 25 mm adjustable air gap <- single LED on MCPCB
     <- thin thermal interface <- aluminum heatsink <- open air
                              driver in a separate side pocket
```

Use the current uFace only as the datum and attachment flange. Enlarge the
external pod to about 60 mm OD or 60 x 60 mm while keeping its centered output
aperture at 30 mm. A 60 mm pod remains inside the uCube's 68 mm overall square
envelope when centered, but it overlaps the 53.2 mm face and must be checked
against neighboring face screws.
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

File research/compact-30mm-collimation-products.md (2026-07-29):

# Compact 30 mm illumination and collimation products

Scope: manufacturer-published products and datasheets relevant to a roughly 30 mm square illuminated face with only 15-20 mm of optical depth. Dimensions below are manufacturer values. "Fits" refers only to the optical envelope, not PCB, heatsink, wiring, or mounting clearance.
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

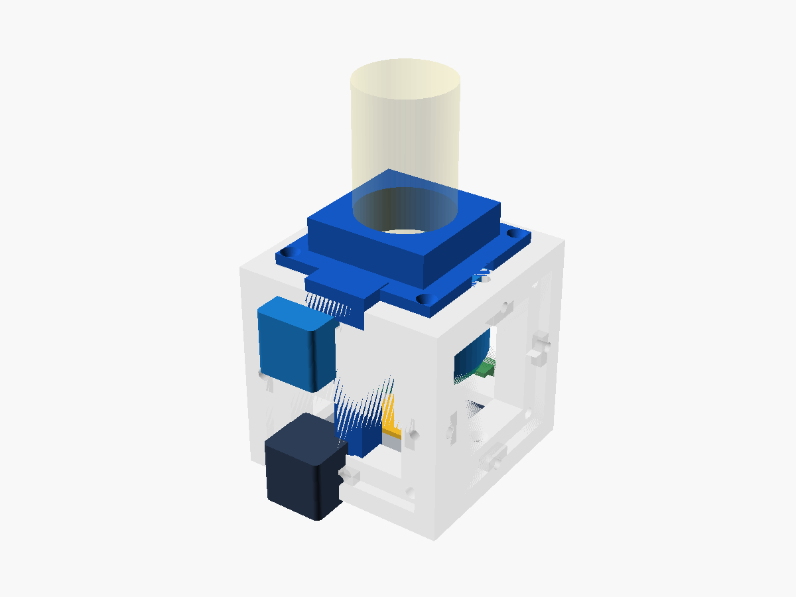
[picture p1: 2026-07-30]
previews/current/adjustable_rail_iso.png

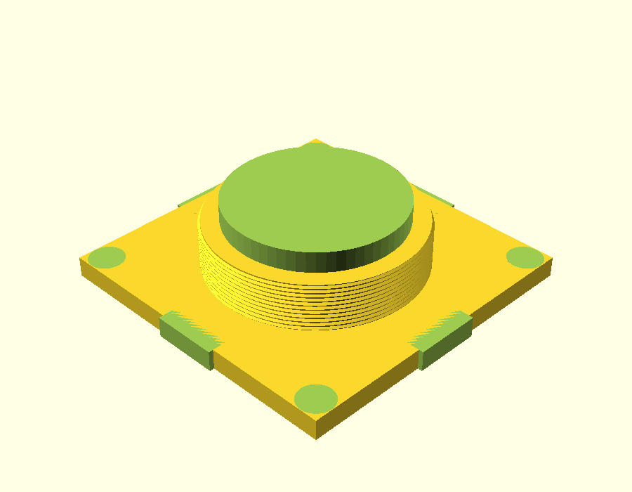
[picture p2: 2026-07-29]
previews/current/camera_face_iso.png

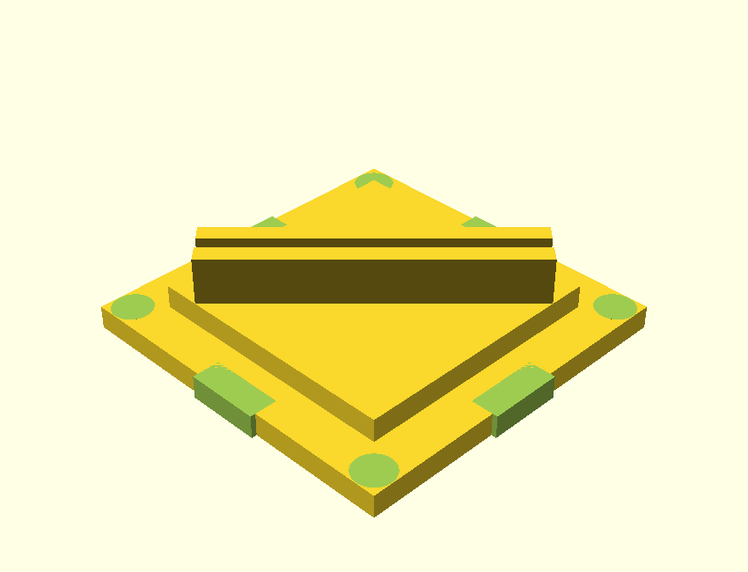
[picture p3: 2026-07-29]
previews/current/beamsplitter_carrier_iso.png

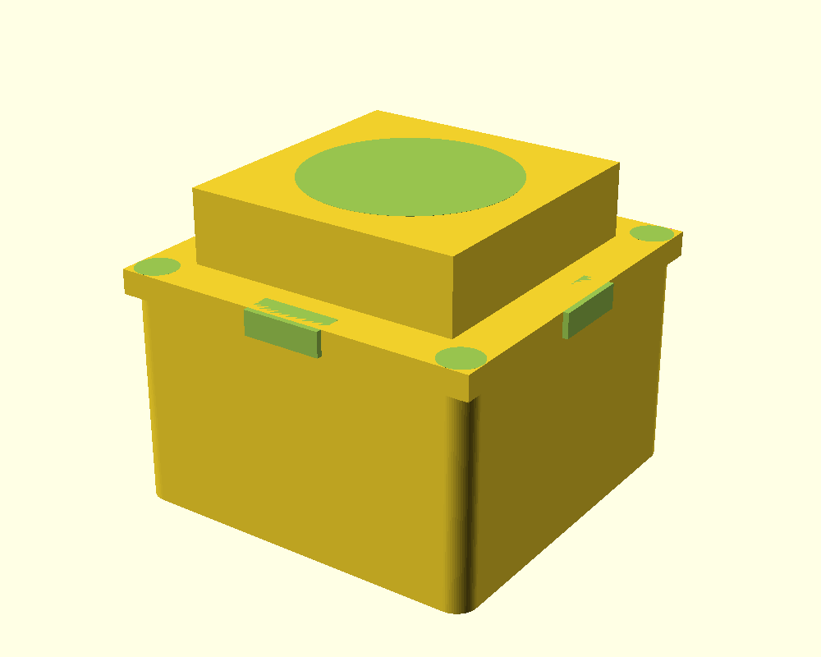
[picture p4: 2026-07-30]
previews/current/condenser_face_cell_iso.png

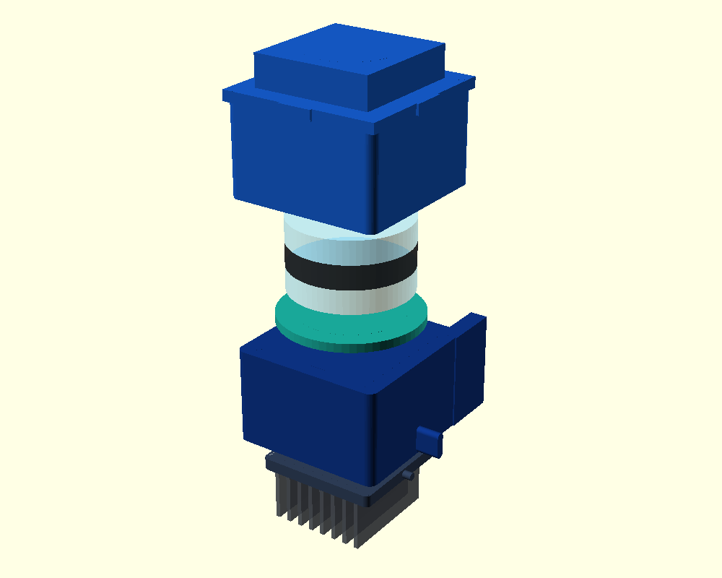
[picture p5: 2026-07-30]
previews/current/condenser_exploded_iso.png

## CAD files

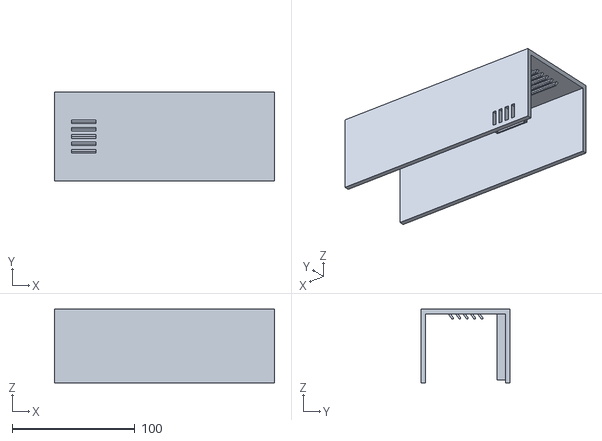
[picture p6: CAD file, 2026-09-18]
exports/current/illumination_cell_top_u.stl
179.5 x 73.0 x 60.2

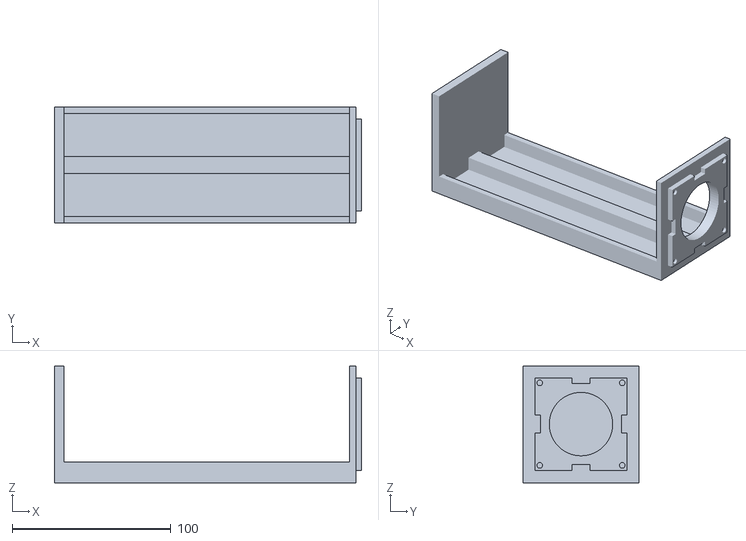
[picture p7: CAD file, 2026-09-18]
exports/current/illumination_cell_bottom_u.stl
193.5 x 73.0 x 73.5

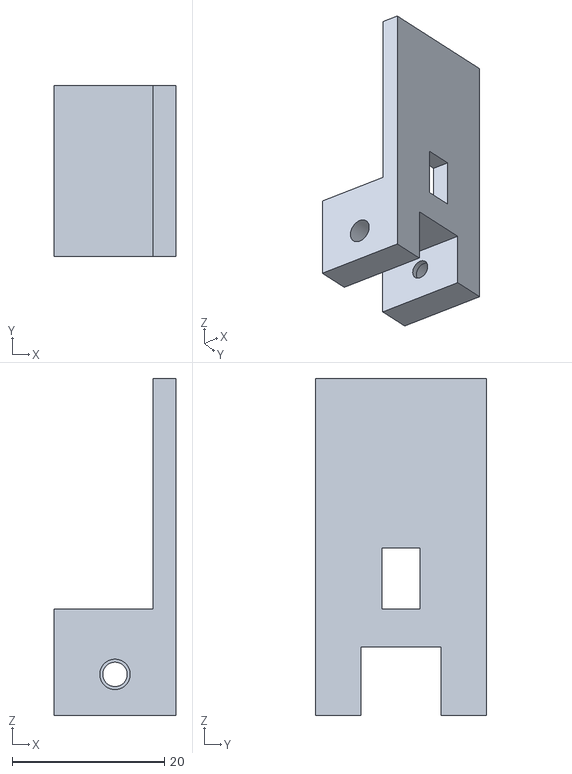
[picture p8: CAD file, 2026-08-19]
exports/current/led_post_slider.stl
16.0 x 22.5 x 44.2

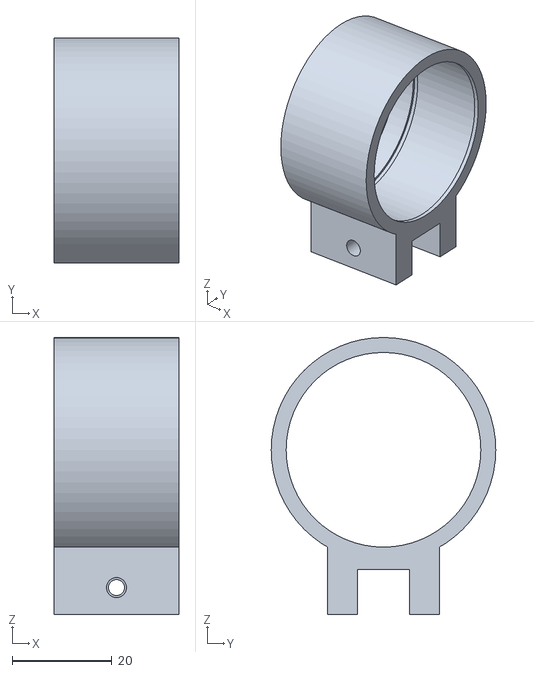
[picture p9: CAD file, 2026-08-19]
exports/current/lens_sleeve_slider.stl
25.0 x 45.0 x 55.5

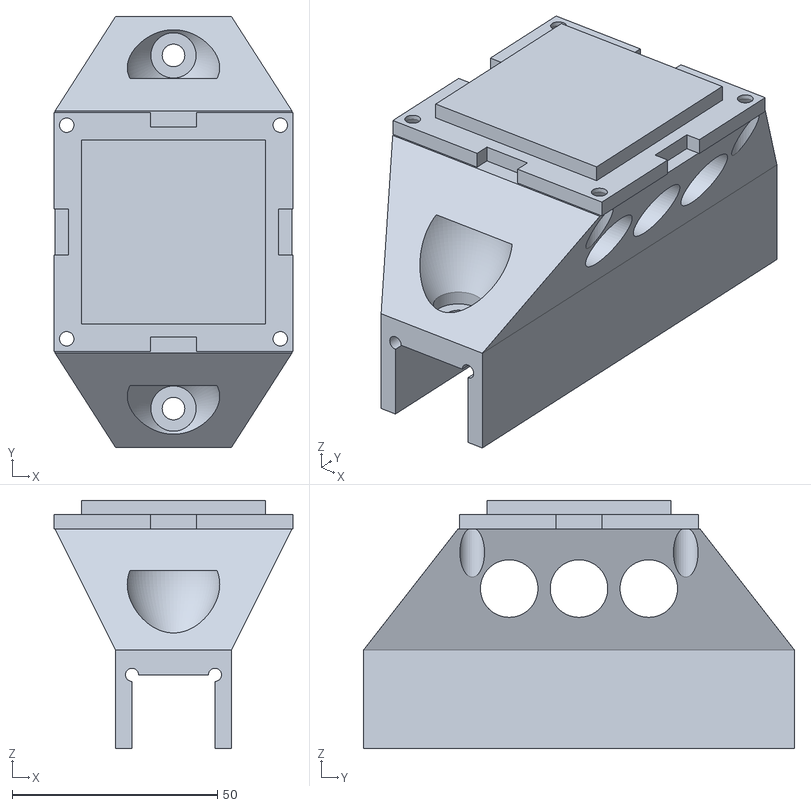
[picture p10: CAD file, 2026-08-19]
exports/current/post_mount.stl
58.2 x 105.0 x 60.5

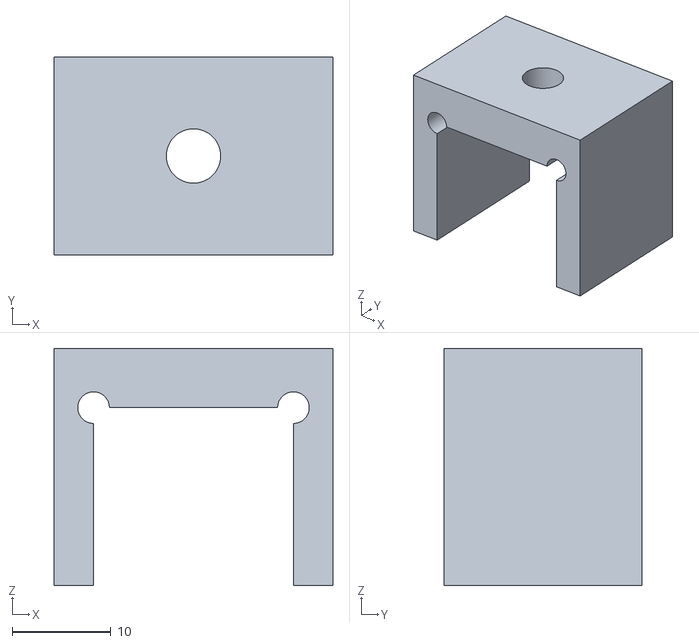
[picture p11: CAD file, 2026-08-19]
exports/current/post_mount_socket_coupon.stl
28.2 x 20.0 x 24.0

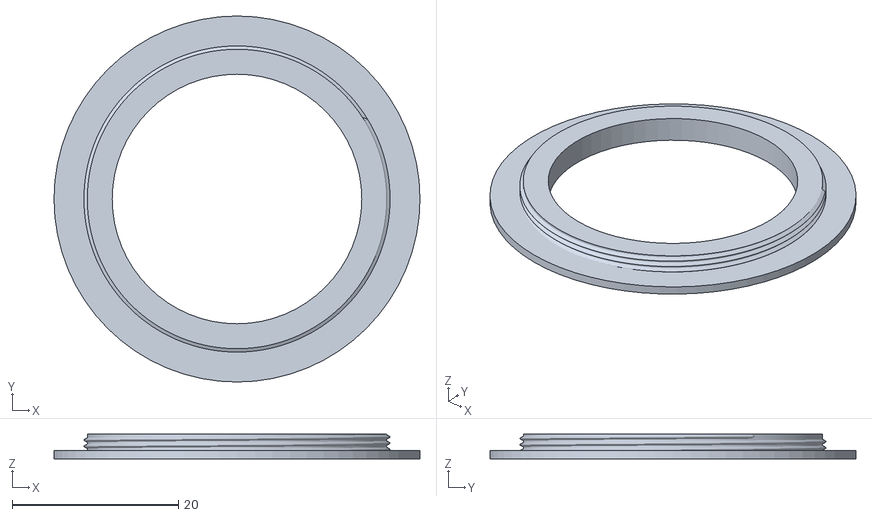
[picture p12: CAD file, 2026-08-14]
exports/current/m37_thread_fit_coupon.stl
44.0 x 44.0 x 3.00

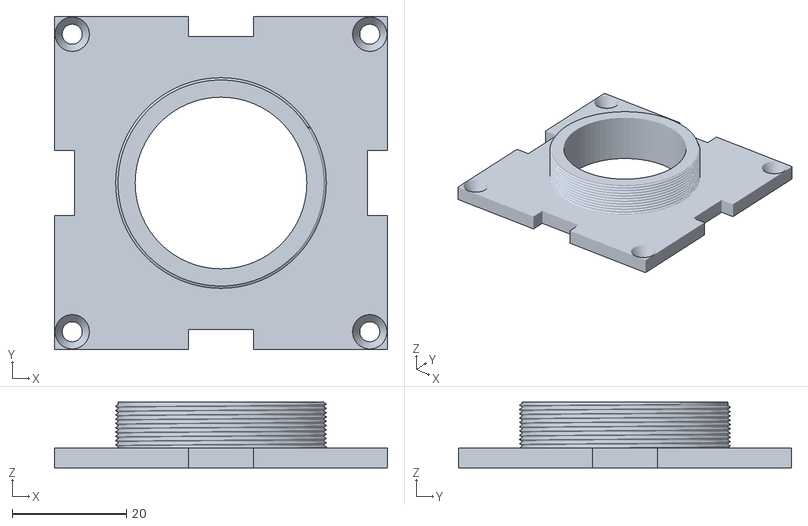
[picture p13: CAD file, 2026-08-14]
exports/current/m37_camera_mounting_face.stl
58.2 x 58.2 x 11.5

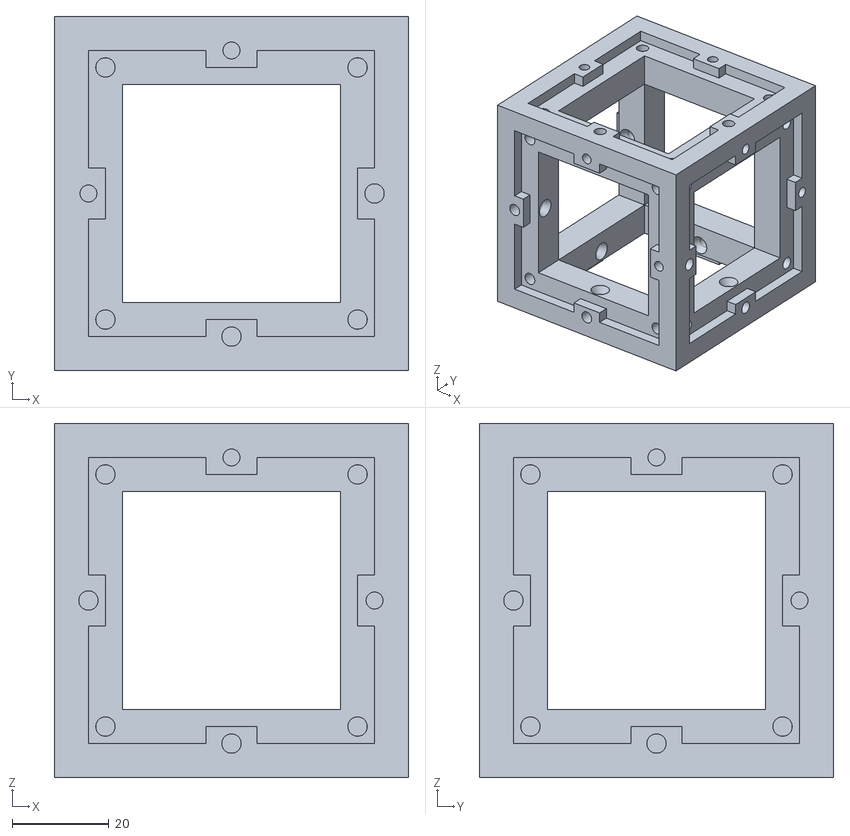
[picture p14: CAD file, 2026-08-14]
exports/current/official_ucube_shell.stl
73.0 x 73.0 x 73.0

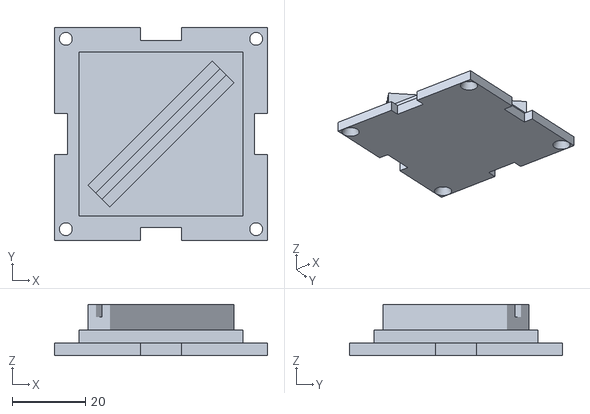
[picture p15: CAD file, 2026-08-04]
exports/current/beamsplitter_mounting_face.stl
58.2 x 58.2 x 14.0

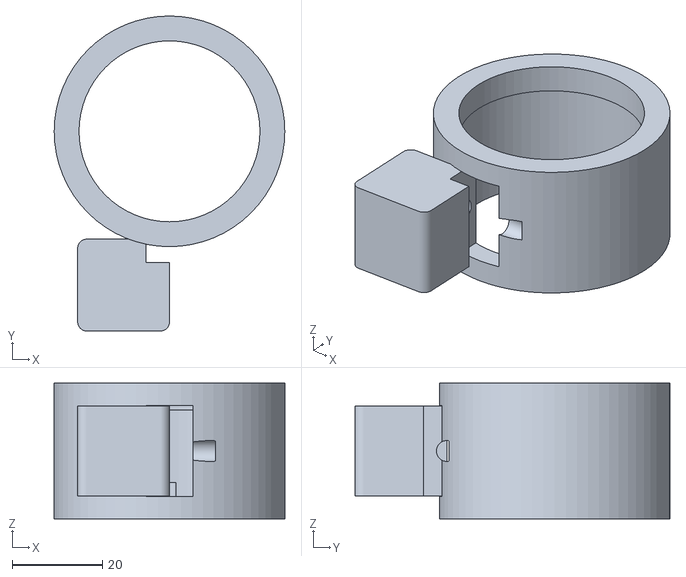
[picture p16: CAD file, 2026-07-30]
exports/current/adjustable_collimator_barrel_slider.stl
51.0 x 69.7 x 30.0

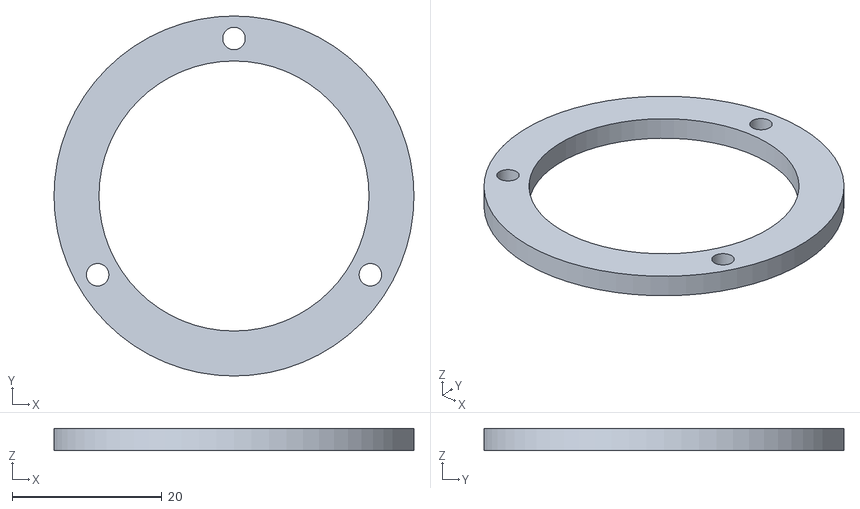
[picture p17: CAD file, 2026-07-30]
exports/current/collimator_retaining_ring.stl
48.0 x 48.0 x 3.00

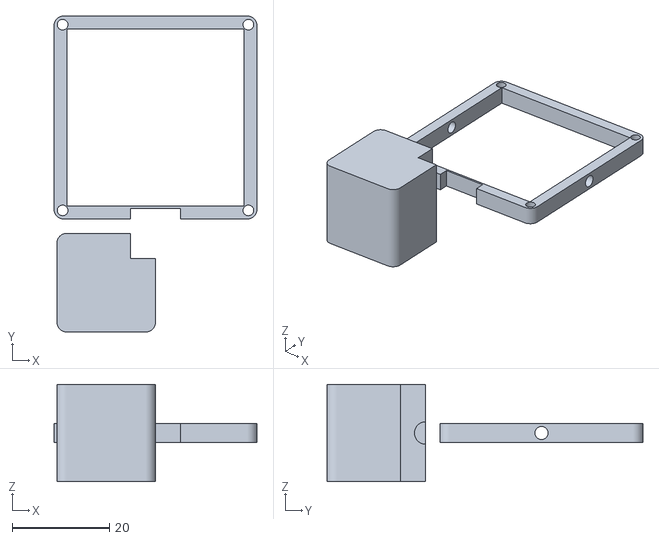
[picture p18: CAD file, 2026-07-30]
exports/current/adjustable_led_heatsink_mount.stl
41.8 x 65.0 x 20.0

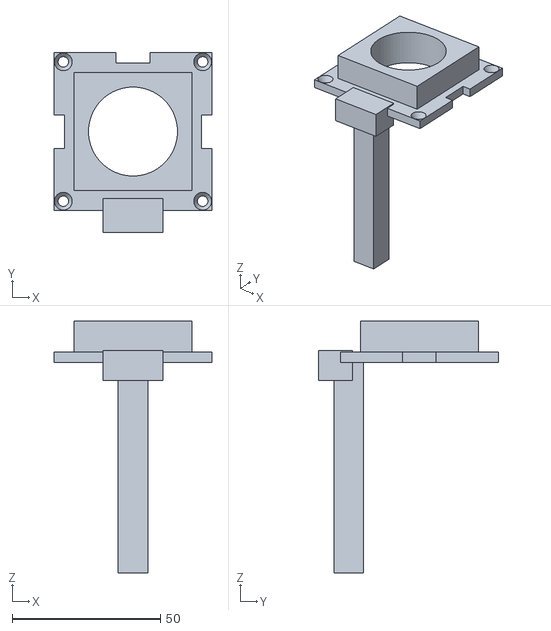
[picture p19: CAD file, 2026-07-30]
exports/current/adjustable_collimator_rail_base.stl
53.2 x 60.6 x 85.0

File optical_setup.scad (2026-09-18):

// Official uCube beamsplitter and compact illumination module.
// render_mode = 0 is the complete live assembly. Press F5 to preview.

include <vendor/BOSL2/std.scad>
include <vendor/BOSL2/threading.scad>
include <vendor/uCube/uCube.scad>

$fn = 64;
epsilon = 0.02;

/* [Preview] */
render_mode = 16; // [0:complete_assembly, 1:beamsplitter_face, 2:legacy_light_face, 3:legacy_back_cover, 4:legacy_optic_cartridge, 5:camera_face, 6:camera_thread_test, 7:exploded_assembly, 8:inspection_assembly, 9:official_ucube_shell, 10:cell_bottom_u, 11:cell_top_u, 12:lens_sleeve_slider, 13:led_post_slider, 14:cell_assembly, 15:cell_assembly_open, 16:post_mount, 17:post_mount_socket_coupon, 18:condenser_carrier, 19:collector_carrier, 20:led_carrier, 21:carrier_foot_coupon]
show_optical_references = true;
camera_preview_detailed_thread = true;
show_auxiliary_illumination_cube = true;
show_legacy_light_chamber = true;
show_post_mount = true;
show_post_stub = true;
post_stub_length_mm = 260; // [80:10:400] Preview only, length of the T-slot post

/* [Official uCube] */
// MEASURED on the physical scaled cube: the square through-hole is 45 mm and
// the wider inside-face inset is 59 mm (= size + 2d), which measures ~60 mm by
// hand. Both of those numbers describe the same cube at size=45, d=7.
internal_clearance_mm = 45; // [40:5:45]
frame_feature_mm = 7; // [7]
face_gap_mm = 0.4; // [0.4]
locator_clearance_mm = 0.2; // [0.1:0.1:0.6]

/* [Beamsplitter] */
plate_width_mm = 50; // [45:0.1:50]
plate_height_mm = 50; // [45:0.1:50]
plate_thickness_mm = 2.5; // [2.5] MEASURED beamsplitter thickness
plate_slot_mm = 2.4; // [2.4] Intentionally undersized for filing to final fit
plate_slot_filing_allowance_mm = 0.1;
plate_slot_interference_mm = plate_thickness_mm - plate_slot_mm;
plate_angle_degrees = 45; // [45]
support_width_mm = 3; // [2:0.25:5]
support_length_mm = 48; // [44:0.5:48]

/* [Light source] */
light_output_diameter_mm = 30; // [25:1:32]
light_body_outer_mm = 48; // [44:1:50]
light_body_inner_mm = 42; // [38:1:44]
light_body_depth_mm = 14.1; // [12:0.5:20]
light_nose_inner_mm = 36; // [34:1:38]
led_board_size_mm = 40; // [30:1:42]
led_plane_setback_mm = 18; // [12:1:20]

/* [Optic cartridge] */
optic_cartridge_size_mm = 34; // [32:1:36]
optic_cartridge_thickness_mm = 1.2; // [0.8:0.2:2]
optic_sheet_size_mm = 32; // [30:1:33]
optic_sheet_thickness_mm = 0.6; // [0.2:0.1:1]
cartridge_fit_clearance_mm = 0.3; // [0.2:0.1:0.6]
cartridge_stop_mm = 0.5; // [0.4:0.1:1]

/* [Rear cover] */
back_cover_thickness_mm = 2.5; // [2:0.5:4]
cover_screw_offset_mm = 20.5; // [19:0.5:21]
cover_screw_radius_mm = 1.2; // [1:0.1:1.6]
cable_notch_mm = 6; // [4:1:9]

// Selected LED: Amazon ASIN B0CL726PBP, 3 W 3535 emitter on 20 mm star MCPCB.
selected_led_power_w = 3;
selected_led_forward_voltage_min_v = 3.0;
selected_led_forward_voltage_max_v = 3.4;
selected_led_drive_current_ma = 700;
selected_led_beam_angle_degrees = 120;
selected_led_cct_min_k = 8000;
selected_led_cct_max_k = 10000;
selected_led_package_mm = 3.5;
provisional_led_board_width_mm = 20; // Selected circular/star board envelope
provisional_led_board_height_mm = 20; // Selected circular/star board envelope
provisional_led_board_thickness_mm = 1.6;
provisional_led_emitter_height_mm = 1.4;


/* [Illumination cell]
   Path B: the illumination optics live in their own light-tight box that bolts
   to one uFace pocket of the optical cube, instead of inside a second official
   cube. An official 73 mm cube has 14 mm end walls, leaving only 45 mm of
   interior along the light axis, which cannot hold the 25 mm sleeve plus focus
   travel plus the LED post. Bolting through a uFace keeps official mounting
   compatibility while letting the box be as long as the optics need.

   The box prints as two U shells: a bottom U (mating plate, floor, far wall,
   integral rail) and a top U (both side walls plus the roof) that drops on as
   a lid. Lifting the lid is how the optics are installed and focused, so no
   access slot or cover strip is needed. */
// The enclosure is wider than its standard 59 mm uFace mounting plate. This
// creates clearance around both slider harnesses without moving cube screws.
cell_outer_span_mm = 73; // [60:1:90] Outside width across the cell
cell_wall_mm = 4; // [3:0.5:6]
cell_end_wall_mm = 6; // [4:0.5:10]
rail_sliding_length_mm = 180; // [120:5:200] Clear full-length slider rail
cell_body_length_mm = rail_sliding_length_mm + cell_wall_mm + cell_end_wall_mm;
cell_aperture_mm = 40; // [30:1:44] Light port through the mating plate
cell_seam_clearance_mm = 0.25; // [0.1:0.05:0.5] Lid slip fit
cell_mount_bridge_depth_mm = 1; // Overlaps the cell wall and uFace by 0.5 mm each

/* [Passive ventilation]
   Short-duration LED use still benefits from passive airflow. Warm air exits
   through roof slots above the LED end while replacement air enters through
   lower slots in one side wall. Internal offset baffles remove the straight
   light path through both slot groups. */
roof_vent_slot_count = 5; // [3:1:7]
roof_vent_slot_length_mm = 20; // [12:1:28] Parallel to the light axis
roof_vent_slot_width_mm = 3; // [2:0.5:5]
roof_vent_slot_pitch_mm = 6; // [5:0.5:9]
side_vent_slot_count = 4; // [2:1:6]
side_vent_slot_width_mm = 3; // [2:0.5:5] Along the light axis
side_vent_slot_height_mm = 12; // [8:1:20] Vertical for support-free wall printing
side_vent_slot_pitch_mm = 6; // [5:0.5:9]
vent_region_from_far_mm = 24; // [18:1:32] Slot-group center from far interior wall
vent_baffle_thickness_mm = 1.2; // [1:0.2:2]
vent_baffle_gap_mm = 5.5; // [2:0.5:6] Balances side-shroud plenum area with intake-slot area
vent_baffle_overlap_mm = 4; // [3:0.5:7] Light-blocking overlap past slot edges
side_intake_positive_y = true;

/* [Lens sleeve, rail, and sliders]
   The two lenses are held on spring clips inside a purchased 40.0 mm lens tube.
   Our sleeve holds that tube: a 1 mm internal lip at the far end stops it, and
   a spring clip in an internal groove retains it. The groove setback is measured
   from the open rear end, opposite the lip. */
tube_outer_mm = 40; // [40] MEASURED purchased lens tube OD
sleeve_clearance_mm = 1.0; // [0.4:0.1:1.6] Total diametral slip fit
sleeve_wall_mm = 2; // [1.5:0.5:3]
sleeve_depth_mm = 25; // [20:1:32] Confirmed against the purchased tube
sleeve_lip_mm = 1; // [0.8:0.1:2] Internal tube stop
sleeve_clip_groove_setback_mm = 5.25; // [5:0.25:5.5] From open rear edge
sleeve_clip_groove_width_mm = 1.25; // [1:0.05:1.5] Axial groove width for the spring
sleeve_clip_groove_radial_depth_mm = 0.5; // [0.25:0.25:1] Recess into sleeve wall
rail_width_mm = 10.5; // [10.5] MEASURED cube screw-pad width
rail_height_mm = 9; // [7:0.5:12]
rail_floor_weld_mm = 0.5; // Rail overlap into the floor for one printable solid
harness_slot_clearance_mm = 0; // [0:0.1:1.4] Nominal zero total width clearance; file as needed
harness_roof_thickness_mm = 1.5; // [1:0.25:3] Solid material above the seated rail
// The harness side runners intentionally rest on the bottom-U floor. The slot
// roof simultaneously rests on the rail top, giving the slider two seating
// datums instead of a floating lower edge.
harness_floor_clearance_mm = 0; // [0:0.05:0.5] Clearance above the bottom-U floor
// The side walls host M3 heat-set inserts end-on. Reuse the official uCube
// screw specification so the cell takes the same inserts as the main cube.
harness_wall_mm = 6; // [6:0.5:9]
lens_harness_length_mm = sleeve_depth_mm; // Full sleeve depth centers its mass over the rail contact
led_harness_length_mm = 16; // [12:1:24] Along the rail
// Shared by both opposing pockets on both the lens and LED slider harnesses.
m3_insert_diameter_mm = 4; // [3.5:0.1:5] Default matches official uCube insert diameter
m3_insert_length_mm = 5; // [3:0.5:8] Default matches official uCube insertH
m3_clamp_clearance_mm = 3.2; // Close M3 clearance leaves a 0.4 mm radial shoulder
m3_clamp_top_margin_mm = 2.0; // Material above clamp passage at rail top
face_mount_clearance_mm = 3.6; // Through-clearance behind each uFace screw
sleeve_setback_mm = 0; // [0:1:30] Preview only, sleeve front from the port
led_gap_mm = 20; // [4:1:34] Preview only, sleeve rear to LED pad
led_star_diameter_mm = 20; // MEASURED star MCPCB envelope
led_post_thickness_mm = 3; // [2.5:0.5:5]
led_cable_notch_mm = 5; // [3:1:8]
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

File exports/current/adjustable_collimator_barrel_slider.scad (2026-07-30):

skip_main_render = true;
include <../../optical_setup.scad>

adjustable_collimator_barrel_slider();

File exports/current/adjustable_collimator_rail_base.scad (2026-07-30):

skip_main_render = true;
include <../../optical_setup.scad>

adjustable_collimator_rail_base();

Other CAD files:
exports/current/adjustable_led_heatsink_mount.scad
exports/current/beamsplitter_mounting_face.scad
exports/current/carrier_foot_coupon_2020.scad
exports/current/carrier_foot_coupon_rail.scad
exports/current/collector_carrier_2020.scad
exports/current/collector_carrier_rail.scad
exports/current/collimator_retaining_ring.scad
exports/current/condenser_carrier_2020.scad
exports/current/condenser_carrier_rail.scad
exports/current/illumination_cell_bottom_u.scad
exports/current/illumination_cell_top_u.scad
exports/current/led_carrier_2020.scad
exports/current/led_carrier_rail.scad
exports/current/led_post_slider.scad
exports/current/lens_sleeve_slider.scad
exports/current/m37_camera_mounting_face.scad
exports/current/m37_thread_fit_coupon.scad
exports/current/official_ucube_shell.scad
exports/current/post_mount.scad
exports/current/post_mount_socket_coupon.scad

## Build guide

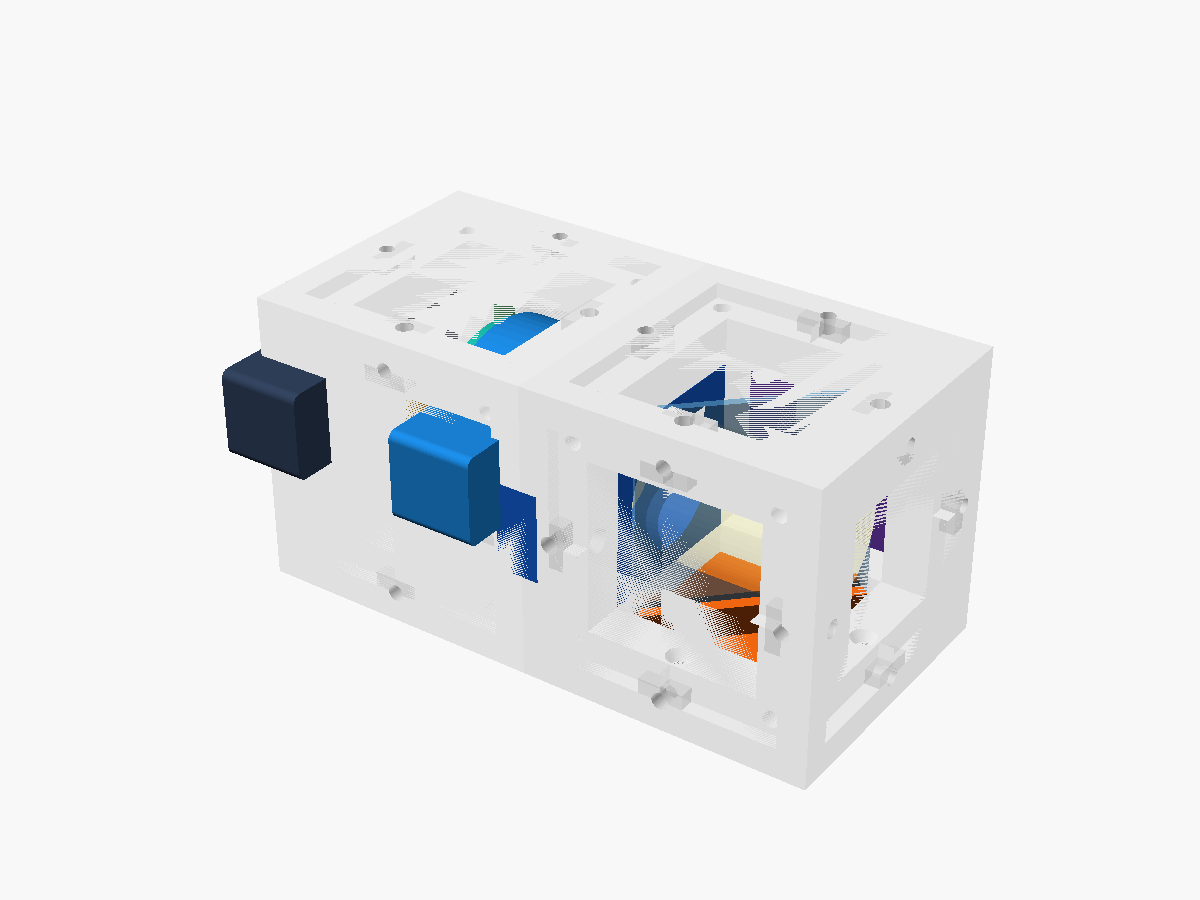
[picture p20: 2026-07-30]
previews/current/assembly_iso.png

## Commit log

2026-07-29 Add BOSL2 dependency and integrate M37 camera face
    [optical_setup.scad]
2026-07-29 Add provisional 50 mm condenser light engine
    [optical_setup.scad]
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2026-07-30 Fit measured 41 mm collimator assembly
    Model the 24.1 mm axial assembly thickness, resize the external pod, and refresh documentation and curated previews.
    [optical_setup.scad]
2026-07-30 Tighten collimator component clearances
    Use 0.2 mm total clearance for the optical pocket, retainer, and LED carriage, and document the supplied split wire clip.
    [optical_setup.scad]
2026-07-30 Record selected light-engine hardware
    Add the measured spring and housing constants, select the 20 mm 3 W LED, and document the axial preload arrangement.
    [optical_setup.scad]
2026-07-30 Add adjustable collimator rail
    Model the transcript-specified 10 mm rail, 10.3 mm slider,
    collimator barrel, LED collar, M3 clamps, and curated previews.
    [optical_setup.scad]
2026-07-30 Enclose collimator rail in auxiliary uCube
    Use the clearer video frames to span the adjustable rail through a
    second uCube cell and keep the slider within its lower frame envelope.
    [optical_setup.scad]
2026-07-30 Publish current printable STL pack
    Add geometry-checked STL exports for the official cube shells,
    mounting faces, adjustable light rail, collimator, LED mount,
    retaining ring, and M37 thread-fit coupon.
    [adjustable_collimator_barrel_slider.stl, adjustable_collimator_rail_base.stl, adjustable_led_heatsink_mount.stl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]
2026-07-30 Add part-specific OpenSCAD exports
    Place a matching SCAD entry file beside every current STL and allow
    the shared source to suppress its normal assembly render when included.
    [adjustable_collimator_barrel_slider.scad, adjustable_collimator_rail_base.scad, adjustable_led_heatsink_mount.scad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]
2026-07-31 Migrate cube geometry from 40 mm to 45 mm clear opening
    The physical scaled cube measures a 45 mm square through-hole, and the
    wider inside-face inset measures ~60 mm by hand. Both describe one cube
    at size=45, d=7: through-hole = size = 45, inset = size + 2d = 59.
    The Scaled_uCube.scad in Downloads carried mySize = 60, which conflated
    the inset with the clear opening and is superseded by the measurement.
    Derived geometry now resolves to 45/59/73 mm. All twenty render modes
    compile clean under --hardwarnings with no assert failures.
    [optical_setup.scad]
2026-07-31 Flip uFace screw counterbores to the outer cube surface
    The vendor uFace cuts its cap-screw counterbores on the plate local +Z.
    Every custom face in this model builds toward the cube interior on +Z, so
    an unmirrored uFace opened all four counterbores inward. Cap screws could
    not seat from outside, which is the reported beamsplitter-holder defect.
    Fixed with a single Z mirror in official_face_at_inside_plane(), so all
    five custom faces are corrected at once and no vendor file changes. The
    plate is symmetric in XY, so nothing moves but the counterbore direction.
    vendor/uCube/Parts/uHolder.scad performs the same flip via rotate([180,0,0]),
    which confirms the intended orientation.
    Verified vis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
    [optical_setup.scad]
2026-07-31 Remove the superseded condenser and collimator-rail family
    The measured 41 mm two-lens assembly this family was built around is
    superseded. The design is now tube-in-tube: a purchased 40.0 mm lens tube
    holds both lenses on spring clips, and our printed sleeve holds the tube.
    The flat-spring retainer, rear retaining ring, LED carriage, heat spreader,
    heatsink, driver rails, and fan envelope all go with it, since v1 strobes
    the LED and needs no secondary heatsink.
    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
    [optical_setup.scad]
2026-07-31 Add the Path B illumination cell shells and integral rail
    The cell is a custom light-tight box that bolts into one uFace pocket of
    the optical cube rather than being a second official cube. Reason: an
    official 73 mm cube has 14 mm end walls, so its interior is only 45 mm
    along the light axis, which cannot hold a 25 mm sleeve plus focus travel
    plus the LED post. Mounting through a uFace keeps official screw
    compatibility while letting the box run as long as the optics need.
    Prints as two U shells. The bottom U carries the mating plate, the near
    end wall with the 40 mm light port, the floor, the far end wall, and the
    integral rail. The top U is both side walls plus the roof and drops on as
    a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
    [optical_setup.scad]
2026-07-31 Add the lens sleeve slider and the LED post slider
    Both sliders share one harness_foot module, so they grip the rail
    identically: a slip-fit U straddling the rail with two opposing M3 set
    screws in heat-set inserts pressing the rail flanks.
    Slider 1 is the lens sleeve as one printed part. Bore 41 for the purchased
    40.0 mm tube, wall 2, OD 45, depth 25. A 1 mm internal lip at the
    cube-facing end stops the tube; the tube loads from the open rear and a
    spring clip retains it. No groove is cut, per the design decision.
    Slider 2 is the LED post: a flat plate with its pad centered on the beam
    axis and a cable pass-through below the star footprint. For v1 the 20 mm
    star is taped or glued on, sinc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
    [optical_setup.scad]
2026-07-31 Wire the illumination cell into the live assemblies
    The cell frame shares global X with the optical cube, so it drops into
    place with a translation only, no rotation. Modes 0, 7, and 8 now show the
    real cell instead of an empty envelope, and the lid is hidden automatically
    in the reference views so the optics stay readable.
    Added mode 14 for the assembled cell and mode 15 for the same cell with the
    lid off, which is the view that shows how the optics actually go in. Also
    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
    [optical_setup.scad]
2026-07-31 Rename the plan document to DESIGN.md and bring it current
    It is no longer a proposal, so proposed_plan.md becomes DESIGN.md and
    AGENTS.md points at the new name.
    Rewrote the stale content. The cube table is now the measured 45/7 geometry
    and flags the Downloads Scaled_uCube.scad as stale. The architecture section
    describes the Path B cell, the single derived-height rail, and the two
    sliders. The superseded 41 mm two-lens assembly, flat-spring retainer, and
    the whole provisional thermal stack are gone, replaced by the purchased
    40.0 mm tube and the strobed no-heatsink v1.
    Added the reasoning behind each decision that was actually contested, a
    render-mode table, and a fit-coupon-first test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
2026-08-01 Lens holder aperatus
    [optical_setup.scad]
2026-08-01 docs: align README with current light cell
    [optical_setup.scad]
2026-08-01 Add separate illumination cell prints
    [illumination_cell_bottom_u.scad, illumination_cell_bottom_u.stl, illumination_cell_top_u.scad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]
2026-08-01 Fix illumination cell mounting and insert geometry
    [optical_setup.scad]
2026-08-01 Make LED post flush with harness
    [optical_setup.scad]
2026-08-01 Refine illumination harness rail fit
    [optical_setup.scad]
2026-08-02 Add reproducible CAD slicing validation
    [beamsplitter_mounting_face.stl, illumination_cell_bottom_u.stl, illumination_cell_top_u.stl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]
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2026-08-03 Improve slider printability and vent lid
    [beamsplitter_mounting_face.stl, illumination_cell_bottom_u.stl, illumination_cell_top_u.stl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]
2026-08-03 Balance illumination cell intake plenum
    [illumination_cell_top_u.stl, optical_setup.scad]
2026-08-04 Center sleeve harness over rail
    [illumination_cell_bottom_u.stl, lens_sleeve_slider.stl, optical_setup.scad]
2026-08-04 Tighten slider rail clearance
    [led_post_slider.stl, lens_sleeve_slider.stl, optical_setup.scad]
2026-08-04 Set sleeve depth to 25 mm
    [led_post_slider.stl, lens_sleeve_slider.stl, optical_setup.scad]
2026-08-04 Fit 2.5 mm beamsplitter plate
    [beamsplitter_mounting_face.stl, optical_setup.scad]
2026-08-13 Tighten harness rail clearance to 0.3 mm
    [led_post_slider.stl, lens_sleeve_slider.stl, optical_setup.scad]
2026-08-14 Seat harness on bottom-U floor
    [illumination_cell_bottom_u.stl, illumination_cell_top_u.stl, led_post_slider.stl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]
2026-08-14 Update lens sleeve export groove
    [lens_sleeve_slider.stl]
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2026-08-18 Add post_mount bracket and fix the vendor face screw pitch
    post_mount is a blank side uFace that flares back 72 mm to a three-sided
    socket over a 2020 T-slot post, replacing the lab clamp that loaded the whole
    optical head through the camera lens barrel. It mounts on the face opposite
    the illumination cell, so the cell's cantilever becomes a pitch moment that
    the tall backplate and the vertically separated M5 bolts resist directly.
    Fixes found by review, all three of which rendered as valid watertight
    manifolds and so were invisible to Simple: yes and check_stl.py:
    - Face screw pitch is now taken from the vendor formula 0.5*(faceSize - d),
    which is 26.0, not (face_outline_mm - frame_feat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
    [optical_setup.scad, post_mount.scad, post_mount_socket_coupon.scad]
2026-08-19 Tighten harness rail fit to nominal zero clearance
    [led_post_slider.stl, lens_sleeve_slider.stl, optical_setup.scad]
2026-08-19 Extend post mount socket depth to 18 mm
    [optical_setup.scad, post_mount.stl, post_mount_socket_coupon.stl]
2026-08-19 Move slider clamp holes clear of rail top
    [led_post_slider.stl, lens_sleeve_slider.stl, optical_setup.scad]
2026-09-18 Add separate-optic carriers with 2020 and printed-rail feet
    Splits the two 40 mm optics onto independent carriers. One cell geometry
    serves both; only the stack length differs. The cell reuses the legacy
    sleeve envelope (41 bore / 45 OD / same clip groove) so the printed-rail
    foot drops onto the existing rail section unchanged, just shorter along X.
    carrier_rail_kind picks the foot: 0 straddles a 2020 extrusion with M5
    into side-slot T-nuts on the extrusion vertical centerline, 1 is the
    legacy printed-rail U-foot.
    Render modes 18-21: condenser_carrier, collector_carrier, led_carrier,
    carrier_foot_coupon.
    [optical_setup.scad]
2026-09-18 Add carrier export entry files for both foot kinds
    carrier_rail_kind is a file-scope assignment, so an entry file cannot
    override it with -D or a pre-include assignment. The carrier modules now
    take kind as an argument defaulting to that global, which lets each of
    the eight entry files pin its own foot.
    [carrier_foot_coupon_2020.scad, carrier_foot_coupon_rail.scad, collector_carrier_2020.scad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]
2026-09-18 Extend illumination rail to 180 mm
    [illumination_cell_bottom_u.stl, illumination_cell_top_u.stl, optical_setup.scad]
